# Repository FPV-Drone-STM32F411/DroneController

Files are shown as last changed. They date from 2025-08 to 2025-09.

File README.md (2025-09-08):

# FPV Drone PCB Full PCB + Code + Assembly

**A comprehensive, fully open-source FPV drone platform**: a two-board avionics stack (flight computer + power/ESC) complete with their codebase *and* a lightweight, robust airframe. All KiCad 9.0 design files, firmware, and CAD are included. Media of all PCBs, schematics and airframe are attached within this repository. 

## Overview

This project develops an FPV drone around two custom 5×5 PCBs: a **STM32F411 flight computer** and a **STM32F405 power distribution + ESC board**. esigned for compatibility with **Betaflight** (FC) and **AM32** (ESC). Both are built around the STM32 chipset and designed to be compatible with BetaFlight and AM32 requirements.

**Manufacturing Sponsor:** Huge thanks to **[PCBWay](https://www.pcbway.com/)** for sponsoring fabrication and assembly of the MKII flight computer. Their high-quality manufacturing, quick turnaround, significantly accelerated the build process. Moreover, their service was excellent and addressed questions promptly and clearly. As a bonus, PCBWay offers affordable, unique **silkscreen colours**. PCBWay is highly recommended and proved to be a great fit for the FPV-Drone-STM32F411 project.

**MKII Flight Computer 3D Model**



**What’s new (MKII & Airframe)**
- **MKII Flight Computer:** UART and SWD flash options, cost-efficient and compact IMU (ICM-42605), oscilloscope-friendly SPI test pads, expanded test points, JST connectors, improved routing for debugability.
- **Open-Source Airframe:** integrated landing legs, structural reinforcements, and geometry to accommodate **~935 KV BLDC motors**; CAD provided for easy printing/mods.

## Airframe

The airframe is designed to be **robust and lightweight** with:
- **Integrated landing legs** and **structural reinforcements** for durability  
- Geometry to suit **~935 KV** brushless motors (modeled in CAD)  
- CAD provided for printing and customization

**Printing tips (suggested):**
- Arms/plates: CF-reinforced nylon or strong PLA+/PETG  
- Landing legs: TPU for impact absorption
- Verify clearances for your chosen motor + prop combo (aimed at 5″ class)

## Hardware Details

 **Integrated PCB Design**
  - Flight Controller: STM32F411CEU6 (ARM Cortex M4)
  - Power/ESC Board: High-current paths, AM32 compatible design
    
 **Connectivity**
  - All peripherals utilize SPI for high-speed sensor communication
  - USB-C, JTAG, SWD
  - UART port for external peripheral
  - Backup Coin Cell Battery Port
  - FTDI programming interface

<ins>**Flight Controller Board**</ins>
- STM32F411CEU6 microcontroller
- 12MHz external crystal oscillator
- ICM-42605 gyroscope/accelerometer
- BMP280 barometer for altitude hold
- L86-M33 GPS for postional tracking
- SX 1276 LoRa 915MHz Transciever NiceRF Module
- Power options, USB-C, LDO and External 3.3V Connection

<ins>**Power and ESC Board**</ins>

**Power System**
- SWD Flash
- DC-DC buck converter for efficient power regulation
- Support for 3S-4S LiPo batteries (11.1V-16.8V)
- XT-60 connector for battery input
- Electric Speed Controller for a BLDC motor

**Electronic Speed Controller (ESC)**
- AM32 compatible
- 10A 935 KV motor capability
- Thermal management design

## Software Compatibility

This drone design is compatible with:
- BetaFlight (recommended for racing/freestyle)
- INAV (for GPS functions)
- Ardupilot (for autonomous capabilities)
- AM32 (for ESC functionality)
- STM32CUBEIDE (Coded in C for entire codebase)

### Bill of Materials

| Component | Description | Specification |
|---|---|---|
| Frame | Open-Source CAD | 5″ class geometry w/ landing legs |
| Motors | Brushless | 935 KV (example: 1800 KV 5″ also viable) |
| Battery | LiPo | 4S 1500mAh 100C (recommended) |
| Propellers | 5-inch | Matched to motor and frame |
| Camera | FPV | CCD or CMOS based on preference |
| Video Transmitter | 5.8GHz | Power output based on needs |
| Receiver | Radio control | Compatible with SX1276 LoRa Transciever |
| LoRa Antenna | 915MHz |SMA compatible quarter-wavelength antenna|

### Electronics Knowledge
- Basic soldering skills
- Understanding of power systems
- Familiarity with microcontrollers
- Ability to flash firmware through CUBEIDE

## Testing Procedures

1. Power system verification (voltage output, regulation)
2. Motor/ESC testing with oscillosocpe
3. SPI testing using oscciloscope test pads
4. Sensor calibration and verification
5. Radio range and failsafe testing
6. Controlled hover tests
7. Full flight testing

# Media
## Most Updated
### Airframe



### MKII of Flight Computer 

**MKII Flight Computer 3D Model**



**MKII Flight Computer PCB**

\

**MKI Flight Computer Schematic**


**MKII Flight Computer Firmware Data Acquistion**

***Disclaimer: GPS outputs are example outputs***

DATA

### MKI of Electric Speed Controller 

**MKI of ESC 3D Model**

ESCV1

**MKI of ESC PCB**



**MKI of ESC Schematic**



## Historical
### MKI of Flight Computer
**MKI Flight Computer 3D Model**



**MKI Flight Computer PCB**



**MKI Flight Computer Schematic**


## Collaboration

This project is in collaboration with Ammar Mahmood and esb8, all PCB designs, CAD modelling, firmware modifications, and build documentation are developed jointly to ensure the highest quality and performance.

## License

This project is released under the MIT License. All design files, including schematics, PCB layouts, and firmware modifications are open source and available for personal and commercial use with attribution.

## Resources

- [PCBWay](https://www.pcbway.com/)
- [BetaFlight Documentation](https://betaflight.com/docs/getting-started/installation)
- [STM32F4 Reference Manual](https://www.st.com/resource/en/reference_manual/rm0383-stm32f411xce-advanced-armbased-32bit-mcus-stmicroelectronics.pdf)
- [ESB8 GitHub Repository](https://github.com/esb8)
- [Ammar Github Repository](https://github.com/ammarjmahmood)
- [Project GitHub Repository](https://github.com/your-username/esb8-fpv-drone)

---
*This FPV drone project aims to combine and create a full documentation on the latest in drone technology with custom-designed electronics to create a high-performance, reliable platform for racing, freestyle, or aerial photography.*

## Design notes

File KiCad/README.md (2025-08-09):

# FPV Drone PCB Full PCB + Assembly

A comprehensive open-source avionics ecosystem for FPV drones featuring a completed flight computer PCB along with in-development power distribution and electronic speed controller PCB. This project delivers an avionics stack for a custom drone with full schematic and PCB files available on KiCad 9.0.

## Overview

This project aims to create a FPV drone with a custom all-in-one (AIO) PCB that combines the flight controller, power distribution, and ESC functionality. Built around the STM32F411CEU6 microcontroller, this drone follows BetaFlight and AM32 design requirements while providing a clean and efficient build.

## Hardware 

 **Integrated PCB Design**
  - Flight Controller: STM32F411CEU6 (ARM Cortex M4)
  - Power Distribution: High-current paths with filtering
  - ESC: AM32 compatible 4-in-1 design
    
 **Connectivity**
  - All peripherals utilize SPI for high-speed sensor communication
  - USB-C, JTAG, SWD
  - UART port for external peripheral
  - Backup Coin Cell Battery Port
  - FTDI programming interface

<ins>**Flight Controller Board**</ins>
- STM32F411CEU6 microcontroller
- 12MHz external crystal oscillator
- ICM-42605 gyroscope/accelerometer
- BMP280 barometer for altitude hold
- L86-M33 GPS for postional tracking
- SX 1276 LoRa 915MHz Transciever NiceRF Module
- Power options, USB-C, LDO and External 3.3V Connection

<ins>**Power and ESC Board**</ins>

**Power System**
- SWD Flash
- DC-DC buck converter for efficient power regulation
- Support for 3S-4S LiPo batteries (11.1V-16.8V)
- XT-60 connector for battery input
- Electric Speed Controller for four BLDC motors

**ESC (Electronic Speed Controller)**
- AM32 compatible
- 30A motor capability
- Thermal management design

## Software Compatibility

This drone design is compatible with:
- BetaFlight (recommended for racing/freestyle)
- INAV (for GPS functions)
- Ardupilot (for autonomous capabilities)
- AM32 (for ESC functionality)

### Bill of Materials

| Component | Description | Specification |
|---|---|---|
| Frame | 3D printed carbon fiber | 5" freestyle/racing frame |
| Motors | Brushless | SpeedyBee 1800KV (recommended) |
| Battery | LiPo | 4S 1500mAh 100C (recommended) |
| Propellers | 5-inch | Matched to motor and frame |
| Camera | FPV | CCD or CMOS based on preference |
| Video Transmitter | 5.8GHz | Power output based on needs |
| Receiver | Radio control | Compatible with SX1276 LoRa Transciever |
| LoRa Antenna | 915MHz |SMA compatible half-dipole antenna|

### Tools
- Soldering iron and solder
- Heat shrink tubing
- Hex drivers/screwdrivers
- LiPo battery charger
- Multimeter
- KiCAD for PCB design modifications
- Zip ties
- Double-sided foam tape

### Electronics Knowledge
- Basic soldering skills
- Understanding of power systems
- Familiarity with microcontrollers
- Ability to flash firmware

## Calculations

### Power System
- Max Current = 4 motors × 30A = 120A
- Required C Rating = 120A / 1.5Ah = 80C minimum
- Flight time estimate = (1500mAh) ÷ (Average current draw) × 60 × 0.8

### Weight Budget
- Target all-up-weight: ~500g (5" freestyle quad)
- Battery weight: ~120-150g (4S 1500mAh)
- Component weight distribution accordingly

## Testing Procedures

1. Power system verification (voltage output, regulation)
2. Motor/ESC testing with oscillosocpe
3. Sensor calibration and verification
4. Radio range and failsafe testing
5. Controlled hover tests
6. Full flight testing

# Media
### MKI of Electric Speed Controller (ESC)

**MKI of ESC 3D Model**



**MKI of ESC PCB**



**MKI of ESC Schematic**



### MKII of Flight Computer (Most Updated)

**MKII Flight Computer 3D Model**



**MKII Flight Computer PCB**



### MKII of Flight Computer
**MKI Flight Computer Schematic**


**MKI Flight Computer 3D Model**



**MKI Flight Computer PCB**



**MKI Flight Computer Schematic**


## Collaboration

This project is in collaboration with Ammar Mahmood and esb8, All PCB designs, firmware modifications, and build documentation are developed jointly to ensure the highest quality and performance.

## License

This project is released under the MIT License. All design files, including schematics, PCB layouts, and firmware modifications are open source and available for personal and commercial use with attribution.

## Resources

- [BetaFlight Documentation](https://betaflight.com/docs/getting-started/installation)
- [STM32F4 Reference Manual](https://www.st.com/resource/en/reference_manual/rm0383-stm32f411xce-advanced-armbased-32bit-mcus-stmicroelectronics.pdf)
- [ESB8 GitHub Repository](https://github.com/esb8)
- [Ammar Github Repository](https://github.com/ammarjmahmood)
- [Project GitHub Repository](https://github.com/your-username/esb8-fpv-drone)

## Contributing

We welcome contributions to this project! If you have suggestions, bug reports, or want to contribute code, please:
1. Fork the repository
2. Create a feature branch
3. Submit a pull request

---
*This FPV drone project aims to combine and create a full documentation on the latest in drone technology with custom-designed electronics to create a high-performance, reliable platform for racing, freestyle, or aerial photography.*

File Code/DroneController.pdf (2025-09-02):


29/08/2025

DroneController Project
Configuration Report

## 1. Description

### 1.1. Project

Project Name | DroneController
Board Name | custom
Generated with: | STM32CubeMX 6.15.0
Date | 08/29/2025

### 1.2. MCU

MCU Series | STM32F4
MCU Line | STM32F411
MCU name | STM32F411CEUx
MCU Package | UFQFPN48
MCU Pin number | 48

### 1.3. Core(s) information

Core(s) | Arm Cortex-M4

## 2. Pinout Configuration

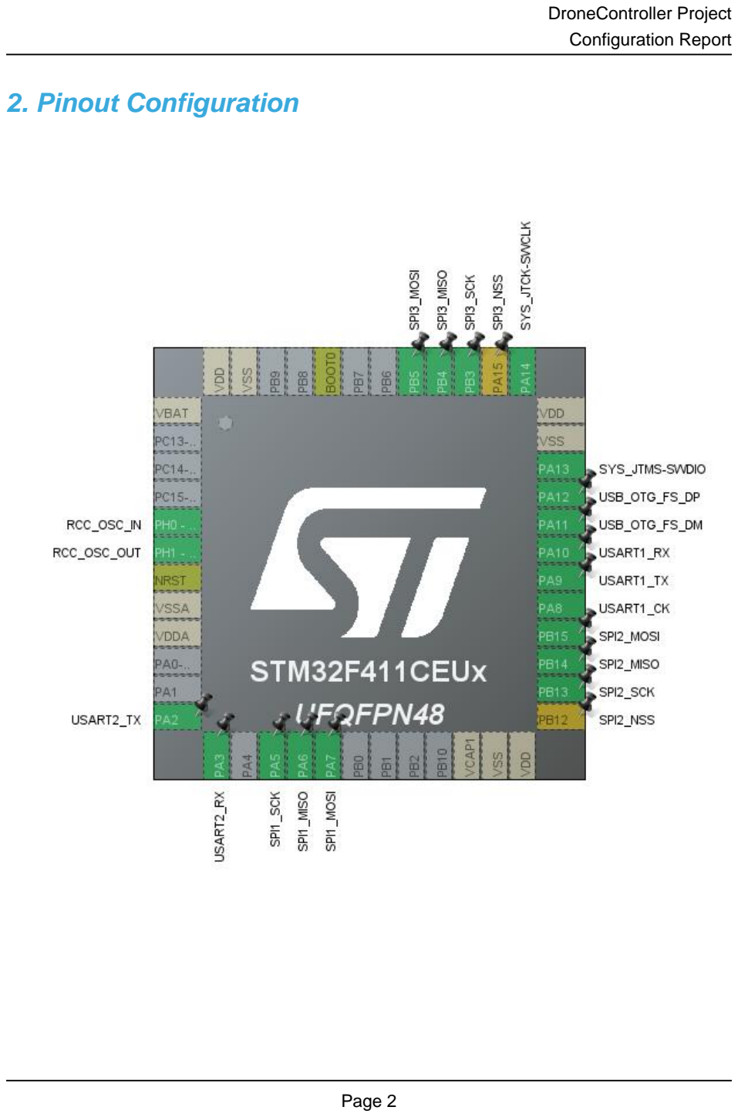
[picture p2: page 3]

## 3. Pins Configuration

Pin Number UFQFPN48 | Pin Name (function after reset) | Pin Type | Alternate Function(s) | Label
1 | VBAT | Power
5 | PH0 - OSC_IN | I/O | RCC_OSC_IN
6 | PH1 - OSC_OUT | I/O | RCC_OSC_OUT
7 | NRST | Reset
8 | VSSA | Power
9 | VDDA | Power
12 | PA2 | I/O | USART2_TX
13 | PA3 | I/O | USART2_RX
15 | PA5 | I/O | SPI1_SCK
16 | PA6 | I/O | SPI1_MISO
17 | PA7 | I/O | SPI1_MOSI
22 | VCAP1 | Power
23 | VSS | Power
24 | VDD | Power
25 | PB12 * | I/O | SPI2_NSS
26 | PB13 | I/O | SPI2_SCK
27 | PB14 | I/O | SPI2_MISO
28 | PB15 | I/O | SPI2_MOSI
29 | PA8 | I/O | USART1_CK
30 | PA9 | I/O | USART1_TX
31 | PA10 | I/O | USART1_RX
32 | PA11 | I/O | USB_OTG_FS_DM
33 | PA12 | I/O | USB_OTG_FS_DP
34 | PA13 | I/O | SYS_JTMS-SWDIO
35 | VSS | Power
36 | VDD | Power
37 | PA14 | I/O | SYS_JTCK-SWCLK
38 | PA15 * | I/O | SPI3_NSS
39 | PB3 | I/O | SPI3_SCK
40 | PB4 | I/O | SPI3_MISO
41 | PB5 | I/O | SPI3_MOSI
44 | BOOT0 | Boot
47 | VSS | Power
48 | VDD | Power

* The pin is affected with a peripheral function but no peripheral mode is activated

## 4. Clock Tree Configuration

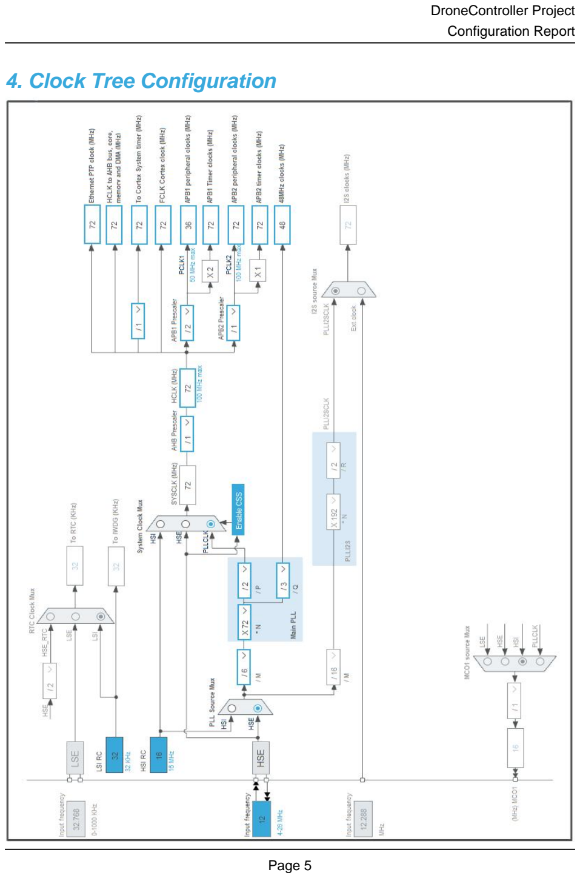
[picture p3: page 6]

## 1. Power Consumption Calculator report

### 1.1. Microcontroller Selection

Series | STM32F4
Line | STM32F411
MCU | STM32F411CEUx
Datasheet | DS10314_Rev6

### 1.2. Parameter Selection

Temperature | 25
Vdd | 1.7

### 1.3. Battery Selection

Battery | Li-SOCL2(A3400)
Capacity | 3400.0 mAh
Self Discharge | 0.08 %/month
Nominal Voltage | 3.6 V
Max Cont Current | 100.0 mA
Max Pulse Current | 200.0 mA
Cells in series | 1
Cells in parallel | 1

### 1.4. Sequence

Step | Step1 | Step2
Mode | RUN | STOP
Vdd | 1.7 | 1.7
Voltage Source | Battery | Battery
Range | Scale1-High | No Scale
Fetch Type | SRAM | n/a
CPU Frequency | 100 MHz | 0 Hz
Clock Configuration | HSE PLL | Regulator_LPLV Flash-PwrDwn
Clock Source Frequency | 4 MHz | 0 Hz
Peripherals
Additional Cons. | 0 mA | 0 mA
Average Current | 12.7 mA | 9 µA
Duration | 0.1 ms | 0.9 ms
DMIPS | 125.0 | 0.0
Ta Max | 104.31 | 105
Category | In DS Table | In DS Table

### 1.5. Results

Sequence Time | 1 ms | Average Current | 1.28 mA
Battery Life | 3 months, 19 days, 6 hours | Average DMIPS | 125.0 DMIPS

### 1.6. Chart

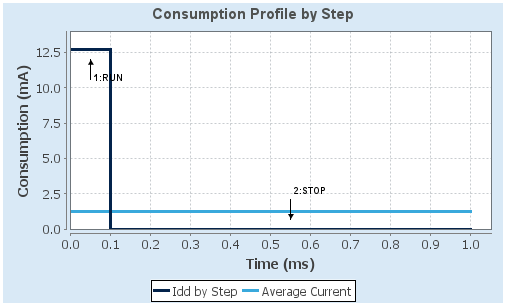
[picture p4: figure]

## 2. Software Project

### 2.1. Project Settings

Name | Value
Project Name | DroneController
Project Folder | C:\Users\evanb\STM32CubeIDE\workspace_1.19.0\DroneController
Toolchain / IDE | STM32CubeIDE
Firmware Package Name and Version | STM32Cube FW_F4 V1.28.3
Application Structure | Advanced
Generate Under Root | Yes
Do not generate the main() | No
Minimum Heap Size | 0x200
Minimum Stack Size | 0x400

### 2.2. Code Generation Settings

Name | Value
STM32Cube MCU packages and embedded software | Copy only the necessary library files
Generate peripheral initialization as a pair of '.c/.h' files | No
Backup previously generated files when re-generating | No
Keep User Code when re-generating | Yes
Delete previously generated files when not re-generated | Yes
Set all free pins as analog (to optimize the power consumption) | No
Enable Full Assert | No

### 2.3. Advanced Settings - Generated Function Calls

Rank | Function Name | Peripheral Instance Name
1 | SystemClock_Config | RCC
2 | MX_GPIO_Init | GPIO
3 | MX_SPI1_Init | SPI1
4 | MX_SPI2_Init | SPI2
5 | MX_SPI3_Init | SPI3
6 | MX_USART1_Init | USART1
7 | MX_USART2_UART_Init | USART2
8 | MX_USB_DEVICE_Init | USB_DEVICE

## 3. Peripherals and Middlewares Configuration

### 3.1. RCC

High Speed Clock (HSE): Crystal/Ceramic Resonator
3.1.1. Parameter Settings:

System Parameters:

VDD voltage (V) | 3.3
Instruction Cache | Enabled
Prefetch Buffer | Enabled
Data Cache | Enabled
Flash Latency(WS) | 2 WS (3 CPU cycle)
RCC Parameters:
HSI Calibration Value | 16
TIM Prescaler Selection | Disabled
HSE Startup Timout Value (ms) | 100
LSE Startup Timout Value (ms) | 5000
Power Parameters:
Power Regulator Voltage Scale | Power Regulator Voltage Scale 1

### 3.2. SPI1

Mode: Full-Duplex Master
3.2.1. Parameter Settings:

Basic Parameters:

Frame Format | Motorola
Data Size | 8 Bits
First Bit | MSB First
Clock Parameters:
Prescaler (for Baud Rate) | 4 *
Baud Rate | 18.0 MBits/s *
Clock Polarity (CPOL) | Low
Clock Phase (CPHA) | 1 Edge
Advanced Parameters:
CRC Calculation | Disabled
NSS Signal Type | Software

### 3.3. SPI2

Mode: Full-Duplex Master
3.3.1. Parameter Settings:

Basic Parameters:

Frame Format | Motorola
Data Size | 8 Bits
First Bit | MSB First
Clock Parameters:
Prescaler (for Baud Rate) | 2
Baud Rate | 18.0 MBits/s *
Clock Polarity (CPOL) | Low
Clock Phase (CPHA) | 1 Edge
Advanced Parameters:
CRC Calculation | Disabled
NSS Signal Type | Software

### 3.4. SPI3

Mode: Full-Duplex Master
3.4.1. Parameter Settings:

Basic Parameters:

Frame Format | Motorola
Data Size | 8 Bits
First Bit | MSB First
Clock Parameters:
Prescaler (for Baud Rate) | 2
Baud Rate | 18.0 MBits/s *
Clock Polarity (CPOL) | Low
Clock Phase (CPHA) | 1 Edge
Advanced Parameters:
CRC Calculation | Disabled
NSS Signal Type | Software

### 3.5. SYS

Debug: Serial Wire
Timebase Source: SysTick

### 3.6. USART1

Mode: Synchronous
3.6.1. Parameter Settings:

Basic Parameters:

Baud Rate | 115200
Word Length | 8 Bits (including Parity)
Parity | None
Stop Bits | 1
Advanced Parameters:
Data Direction | Receive and Transmit
Clock Parameters:
Clock Polarity | Low
Clock Phase | One Edge
Clock Last Bit | Disable

### 3.7. USART2

Mode: Asynchronous
3.7.1. Parameter Settings:

Basic Parameters:

Baud Rate | 115200
Word Length | 8 Bits (including Parity)
Parity | None
Stop Bits | 1
Advanced Parameters:
Data Direction | Receive and Transmit
Over Sampling | 16 Samples

### 3.8. USB_OTG_FS

Mode: Device_Only

3.8.1. Parameter Settings:
Speed | Device Full Speed 12MBit/s
Low power | Disabled
Link Power Management | Disabled
VBUS sensing | Disabled
Signal start of frame | Disabled

### 3.9. USB_DEVICE

Class For FS IP: Communication Device Class (Virtual Port Com)
3.9.1. Parameter Settings:

Basic Parameters:

USBD_MAX_NUM_INTERFACES (Maximum number of supported interfaces) | 1
USBD_MAX_NUM_CONFIGURATION (Maximum number of supported configuration) | 1
USBD_MAX_STR_DESC_SIZ (Maximum size for the string descriptors) | 512
USBD_SELF_POWERED (Enabled self power) | Enabled
USBD_DEBUG_LEVEL (USBD Debug Level) | 0: No debug message
Class Parameters:
USB CDC Rx Buffer Size | 2048
USB CDC Tx Buffer Size | 2048
3.9.2. Device Descriptor:

Device Descriptor:

VID (Vendor IDentifier) | 1155
LANGID_STRING (Language Identifier) | English(United States)
MANUFACTURER_STRING (Manufacturer Identifier) | STMicroelectronics
Device Descriptor FS:
PID (Product IDentifier) | 22336
PRODUCT_STRING (Product Identifier) | STM32 Virtual ComPort
CONFIGURATION_STRING (Configuration Identifier) | CDC Config
INTERFACE_STRING (Interface Identifier) | CDC Interface

* User modified value

## 4. System Configuration

### 4.1. GPIO configuration

IP | Pin | Signal | GPIO mode | GPIO pull/up pull down

Max
Speed

User Label

RCC | PH0 - OSC_IN | RCC_OSC_IN | n/a | n/a | n/a
| PH1 - OSC_OUT | RCC_OSC_OUT | n/a | n/a | n/a
SPI1 | PA5 | SPI1_SCK | Alternate Function Push Pull | No pull-up and no pull-down | Very High
*
| PA6 | SPI1_MISO | Alternate Function Push Pull | No pull-up and no pull-down | Very High
*
| PA7 | SPI1_MOSI | Alternate Function Push Pull | No pull-up and no pull-down | Very High
*
SPI2 | PB13 | SPI2_SCK | Alternate Function Push Pull | No pull-up and no pull-down | Very High
*
| PB14 | SPI2_MISO | Alternate Function Push Pull | No pull-up and no pull-down | Very High
*
| PB15 | SPI2_MOSI | Alternate Function Push Pull | No pull-up and no pull-down | Very High
*
SPI3 | PB3 | SPI3_SCK | Alternate Function Push Pull | No pull-up and no pull-down | Very High
*
| PB4 | SPI3_MISO | Alternate Function Push Pull | No pull-up and no pull-down | Very High
*
| PB5 | SPI3_MOSI | Alternate Function Push Pull | No pull-up and no pull-down | Very High
*
SYS | PA13 | SYS_JTMS- SWDIO | n/a | n/a | n/a
| PA14 | SYS_JTCK- SWCLK | n/a | n/a | n/a
USART1 | PA8 | USART1_CK | Alternate Function Push Pull | No pull-up and no pull-down | Very High
*
| PA9 | USART1_TX | Alternate Function Push Pull | No pull-up and no pull-down | Very High
*
| PA10 | USART1_RX | Alternate Function Push Pull | No pull-up and no pull-down | Very High
*
USART2 | PA2 | USART2_TX | Alternate Function Push Pull | No pull-up and no pull-down | Very High
*

IP | Pin | Signal | GPIO mode | GPIO pull/up pull down | Max Speed | User Label
| PA3 | USART2_RX | Alternate Function Push Pull | No pull-up and no pull-down | Very High *
USB_OTG_ FS | PA11 | USB_OTG_FS_ DM | Alternate Function Push Pull | No pull-up and no pull-down | Very High *
| PA12 | USB_OTG_FS_ DP | Alternate Function Push Pull | No pull-up and no pull-down | Very High *
Single Mapped Signals | PB12 | SPI2_NSS | Alternate Function Push Pull | No pull-up and no pull-down | Very High *
| PA15 | SPI3_NSS | Alternate Function Push Pull | No pull-up and no pull-down | Very High *

### 4.2. DMA configuration

nothing configured in DMA service

### 4.3. NVIC configuration

4.3.1. NVIC
Interrupt Table | Enable | Preenmption Priority | SubPriority
Non maskable interrupt | true | 0 | 0
Hard fault interrupt | true | 0 | 0
Memory management fault | true | 0 | 0
Pre-fetch fault, memory access fault | true | 0 | 0
Undefined instruction or illegal state | true | 0 | 0
System service call via SWI instruction | true | 0 | 0
Debug monitor | true | 0 | 0
Pendable request for system service | true | 0 | 0
System tick timer | true | 15 | 0
USB On The Go FS global interrupt | true | 0 | 0
PVD interrupt through EXTI line 16 | unused
Flash global interrupt | unused
RCC global interrupt | unused
SPI1 global interrupt | unused
SPI2 global interrupt | unused
USART1 global interrupt | unused
USART2 global interrupt | unused
SPI3 global interrupt | unused
FPU global interrupt | unused
4.3.2. NVIC Code generation
Enabled interrupt Table | Select for init sequence ordering | Generate IRQ handler | Call HAL handler
Non maskable interrupt | false | true | false
Hard fault interrupt | false | true | false
Memory management fault | false | true | false
Pre-fetch fault, memory access fault | false | true | false
Undefined instruction or illegal state | false | true | false
System service call via SWI instruction | false | true | false
Debug monitor | false | true | false
Pendable request for system service | false | true | false
System tick timer | false | true | true
USB On The Go FS global interrupt | false | true | true

* User modified value

## 5. System Views

5.1. Category view
5.1.1. Current

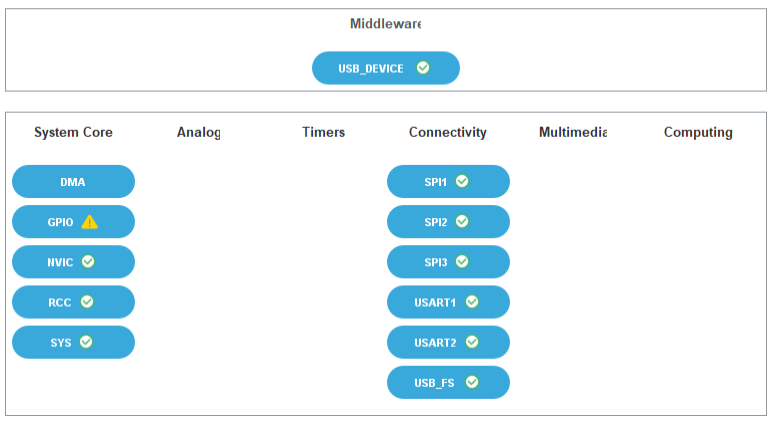
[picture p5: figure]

## 6. Docs & Resources

Type | Link
BSDL files | https://www.st.com/resource/en/bsdl_model/stm32f411_bsdl.zip
IBIS models | https://www.st.com/resource/en/ibis_model/stm32f411_ibis.zip
System View Description | https://www.st.com/resource/en/svd/stm32f4-svd.zip
Presentations | https://www.st.com/resource/en/product_presentation/stm32-stm8_embedded_software_solutions.pdf
Presentations | https://www.st.com/resource/en/product_presentation/stm32_eval-tools_portfolio.pdf
Presentations | https://www.st.com/resource/en/product_presentation/stm32_stm8_functi onal-safety-packages.pdf
Presentations | https://www.st.com/resource/en/product_presentation/stm32-stm8_software_development_tools.pdf
Presentations | https://www.st.com/resource/en/product_presentation/microcontrollers-stm32-family-overview.pdf
Brochures | https://www.st.com/resource/en/brochure/products-and-solutions-for-plcs-and-smart-i-os.pdf
Flyers | https://www.st.com/resource/en/flyer/flstm32f4x1.pdf
Flyers | https://www.st.com/resource/en/flyer/flstm32nucleo.pdf
Flyers | https://www.st.com/resource/en/flyer/flstm32trust.pdf
Product Certifications | https://www.st.com/resource/en/certification_document/stm32_authentication_can.pdf
Security Bulletin | https://www.st.com/resource/en/technical_note/tn1489-security-bulletin-tn1489stpsirt-physical-attacks-on-stm32-and-stm32cube-firmware-stmicroelectronics.pdf
Application Notes | https://www.st.com/resource/en/application_note/an1709-emc-design-guide-for-stm8-stm32-and-legacy-mcus-stmicroelectronics.pdf
Application Notes | https://www.st.com/resource/en/application_note/an2606-stm32-microcontroller-system-memory-boot-mode-stmicroelectronics.pdf
Application Notes | https://www.st.com/resource/en/application_note/an2945-stm8s-and-

| stm32-mcus-a-consistent-832bit-product-line-for-painless-migration-stmicroelectronics.pdf
Application Notes | https://www.st.com/resource/en/application_note/an3070-managing-the-driver-enable-signal-for-rs485-and-iolink-communications-with-the-stm32s-usart-stmicroelectronics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
Application Notes | https://www.st.com/resource/en/application_note/an3126-audio-and-waveform-generation-using-the-dac-in-stm32-products-stmicroelectronics.pdf
Application Notes | https://www.st.com/resource/en/application_note/an3155-usart-protocol-used-in-the-stm32-bootloader-stmicroelectronics.pdf
Application Notes | https://www.st.com/resource/en/application_note/an3156-usb-dfu-protocol-used-in-the-stm32-bootloader-stmicroelectronics.pdf
Application Notes | https://www.st.com/resource/en/application_note/an3364-migration-and-compatibility-guidelines-for-stm32-microcontroller-applications-stmicroelectronics.pdf
Application Notes | https://www.st.com/resource/en/application_note/an3997-audio-playback-and-recording-using-the-stm32f4discovery-stmicroelectronics.pdf
Application Notes | https://www.st.com/resource/en/application_note/an3998-pdm-audio-software-decoding-on-stm32-microcontrollers-stmicroelectronics.pdf
Application Notes | https://www.st.com/resource/en/application_note/an4031-using-the-stm32f2-stm32f4-and-stm32f7-series-dma-controller-stmicroelectronics.pdf
Application Notes | https://www.st.com/resource/en/application_note/an4221-i2c-protocol-used-in-the-stm32-bootloader-stmicroelectronics.pdf
Application Notes | https://www.st.com/resource/en/application_note/an4286-spi-protocol-used-in-the-stm32-bootloader-stmicroelectronics.pdf
Application Notes | https://www.st.com/resource/en/application_note/an4488-getting-started-with-stm32f4xxxx-mcu-hardware-development-stmicroelectronics.pdf
Application Notes | https://www.st.com/resource/en/application_note/an4616-migrating-from-stm32f401-and-stm32f411-lines-to-stm32l4-series-and-stm32l4-series-microcontrollers-stmicroelec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
Application Notes | https://www.st.com/resource/en/application_note/an4646-peripheral- interconnections-on-stm32f401-and-stm32f411-lines-

| stmicroelectronics.pdf
Application Notes | https://www.st.com/resource/en/application_note/an4655-virtually-increasing-the-number-of-serial-communication-peripherals-in-stm32-applications-stmicroelectronics.p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
Application Notes | https://www.st.com/resource/en/application_note/an4739-stm32cube-firmware-examples-for-stm32f4-series-stmicroelectronics.pdf
Application Notes | https://www.st.com/resource/en/application_note/an4750-handling-of-soft-errors-in-stm32-applications-stmicroelectronics.pdf
Application Notes | https://www.st.com/resource/en/application_note/an4776-generalpurpose-timer-cookbook-for-stm32-microcontrollers-stmicroelectronics.pdf
Application Notes | https://www.st.com/resource/en/application_note/an4803-highspeed-si-simulations-using-ibis-and-boardlevel-simulations-using-hyperlynx-si-on-stm32-mcus-and-mpus-stmic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
Application Notes | https://www.st.com/resource/en/application_note/an4850-stm32-mcus-spreadspectrum-clock-generation-principles-properties-and-implementation-stmicroelectronics.pdf
Application Notes | https://www.st.com/resource/en/application_note/an4904-migration-of-microcontroller-applications-from-stm32f1-series-to-stm32f4-access-lines-stmicroelectronics.pdf
Application Notes | https://www.st.com/resource/en/application_note/an4989-stm32-microcontroller-debug-toolbox-stmicroelectronics.pdf
Application Notes | https://www.st.com/resource/en/application_note/an4995-using-an-electromyogram-technique-to-detect-muscle-activity-stmicroelectronics.pdf
Application Notes | https://www.st.com/resource/en/application_note/an5027-interfacing-pdm-digital-microphones-using-stm32-mcus-and-mpus-stmicroelectronics.pdf
Application Notes | https://www.st.com/resource/en/application_note/an5073-receiving-spdif-audio-stream-with-the-stm32f4f7h7-series-stmicroelectronics.pdf
Application Notes | https://www.st.com/resource/en/application_note/an4899-stm32-microcontroller-gpio-hardware-settings-and-lowpower-consumption-stmicroelectronics.pdf
Application Notes | https://www.st.com/resource/en/application_note/an5612-esd-protection-of-stm32-mcus-and-mpus-stmicroelectronics.pdf

Application Notes | https://www.st.com/resource/en/application_note/an4838-introduction-to-memory-protection-unit-management-on-stm32-mcus-stmicroelectronics.pdf
Application Notes | https://www.st.com/resource/en/application_note/an5852-migrating-from-stm32f401-stm32f410-and-stm32f411-to-stm32h503-mcus-stmicroelectronics.pdf
Application Notes | https://www.st.com/resource/en/application_note/an4879-introduction-to-usb-hardware-and-pcb-guidelines-using-stm32-mcus-stmicroelectronics.pdf
Application Notes | https://www.st.com/resource/en/application_note/an5225-introduction-to-usb-typec-power-delivery-for-stm32-mcus-and-mpus-stmicroelectronics.pdf
Application Notes | https://www.st.com/resource/en/application_note/an5537-how-to-use-adc-oversampling-techniques-to-improve-signaltonoise-ratio-on-stm32-mcus-stmicroelectronics.pdf
Application Notes | https://www.st.com/resource/en/application_note/an5036-guidelines-for-thermal-management-on-stm32-applications-stmicroelectronics.pdf
Application Notes | https://www.st.com/resource/en/application_note/an4230-introduction-to-random-number-generation-validation-using-the-nist-statistical-test-suite-for-stm32-mcus-and-m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
Application Notes | https://www.st.com/resource/en/application_note/an2867-guidelines-for-oscillator-design-on-stm8afals-and-stm32-mcusmpus-stmicroelectronics.pdf
Application Notes | https://www.st.com/resource/en/application_note/an4013-introduction-to-timers-for-stm32-mcus-stmicroelectronics.pdf
Application Notes | https://www.st.com/resource/en/application_note/an4277-how-to-use-pwm-shutdown-for-motor-control-and-digital-power-conversion-on-stm32-mcus-stmicroelectronics.pdf
Application Notes | https://www.st.com/resource/en/application_note/an4759-introduction-to-using-the-hardware-realtime-clock-rtc-and-the-tamper-management-unit-tamp-with-stm32-mcus-stmi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
Application Notes | https://www.st.com/resource/en/application_note/an4908-getting-started-with-usart-automatic-baud-rater-detection-for-stm32-mcus-stmicroelectronics.pdf

Application Notes | https://www.st.com/resource/en/application_note/an5156-introduction-to-security-for-stm32-mcus-stmicroelectronics.pdf
Application Notes | https://www.st.com/resource/en/application_note/an5543-guidelines-for-enhanced-spi-communication-on-stm32-mcus-and-mpus-stmicroelectronics.pdf
Application Notes | https://www.st.com/resource/en/application_note/cd00211314-how-to-optimize-the-adc-accuracy-in-the-stm32-mcus-stmicroelectronics.pdf
Application Notes | https://www.st.com/resource/en/application_note/an2639-soldering-recommendations-and-package-information-for-leadfree-ecopack2-mcus-and-mpus-stmicroelectronics.pdf
Application Notes | https://www.st.com/resource/en/application_note/an3154-how-to-use-can-protocol-in-bootloader-on-stm32-mcus-stmicroelectronics.pdf
Application Notes | https://www.st.com/resource/en/application_note/an4566-how-to-extend-the-dac-performance-on-stm32-mcus-stmicroelectronics.pdf
Application Notes for related Tools & Software | https://www.st.com/resource/en/application_note/an2656-stm32f10xxx-lcd-glass-driver-firmware-stmicroelectronics.pdf
Application Notes for related Tools & Software | https://www.st.com/resource/en/application_note/an2790-tft-lcd-interfacing-with-the-highdensity-stm32f10xxx-fsmc-stmicroelectronics.pdf
Application Notes for related Tools & Software | https://www.st.com/resource/en/application_note/an3078-stm32-inapplication-programming-over-the-ic-bus-stmicroelectronics.pdf
Application Notes for related Tools & Software | https://www.st.com/resource/en/application_note/an3116-stm32s-adc-modes-and-their-applications-stmicroelectronics.pdf
Application Notes for related Tools & Software | https://www.st.com/resource/en/application_note/an3174-implementing-receivers-for-infrared-remote-control-protocols-using-stm32f10xxx-microcontrollers-stmicroelectro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
Application Notes for related Tools & Software | https://www.st.com/resource/en/application_note/an3241-qvga-tftlcd-direct-drive-using-the-stm32f10xx-fsmc-peripheral-stmicroelectronics.pdf

Application Notes
for related Tools

https://www.st.com/resource/en/application_note/an3307-guidelines-forobtaining-iec-60335-class-b-certification-for-any-stm32-application-

& Software | stmicroelectronics.pdf
Application Notes for related Tools & Software | https://www.st.com/resource/en/application_note/an3965-stm32f40xstm32f41x-inapplication-programming-using-the-usart-stmicroelectronics.pdf
Application Notes for related Tools & Software | https://www.st.com/resource/en/application_note/an3969-eeprom-emulation-in-stm32f40xstm32f41x-microcontrollers-stmicroelectronics.pdf
Application Notes for related Tools & Software | https://www.st.com/resource/en/application_note/an4044-floating-point-unit-demonstration-on-stm32-microcontrollers-stmicroelectronics.pdf
Application Notes for related Tools & Software | https://www.st.com/resource/en/application_note/an4323-getting-started-with-stemwin-library-stmicroelectronics.pdf
Application Notes for related Tools & Software | https://www.st.com/resource/en/application_note/an4365-using-stm32f4-mcu-power-modes-with-best-dynamic-efficiency-stmicroelectronics.pdf
Application Notes for related Tools & Software | https://www.st.com/resource/en/application_note/an4435-guidelines-for-obtaining-ulcsaiec-607301603351-class-b-certification-in-any-stm32-application-stmicroelectroni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
Application Notes for related Tools & Software | https://www.st.com/resource/en/application_note/an4457-implementing-an-emulated-uart-on-stm32f4-microcontrollers-stmicroelectronics.pdf
Application Notes for related Tools & Software | https://www.st.com/resource/en/application_note/an4499-stm32--nrf51822-bluetooth-low-energy-system-solution-stmicroelectronics.pdf
Application Notes for related Tools & Software | https://www.st.com/resource/en/application_note/an4515-using-batch-acquisition-mode-bam-to-maximize-power-efficiency-on-stm32f410-stm32f411-stm32f412-stm32f413-micro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
Application Notes for related Tools & Software | https://www.st.com/resource/en/application_note/an4657-stm32-inapplication-programming-iap-using-the-usart-stmicroelectronics.pdf

Application Notes
for related Tools

https://www.st.com/resource/en/application_note/an4666-parallelsynchronous-transmission-using-gpio-and-dma-stmicroelectronics.pdf

& Software
Application Notes for related Tools & Software | https://www.st.com/resource/en/application_note/an4678-full-duplex-spi-emulation-for-stm32f4-microcontrollers-stmicroelectronics.pdf
Application Notes for related Tools & Software | https://www.st.com/resource/en/application_note/an4701-proprietary-code-readout-protection-on-microcontrollers-of-the-stm32f4-series-stmicroelectronics.pdf
Application Notes for related Tools & Software | https://www.st.com/resource/en/application_note/an4739-stm32cube-firmware-examples-for-stm32f4-series-stmicroelectronics.pdf
Application Notes for related Tools & Software | https://www.st.com/resource/en/application_note/an4758-proprietary-code-readout-protection-on-stm32l4-stm32l4-stm32g4-and-stm32wb-series-mcus-stmicroelectronics.pdf
Application Notes for related Tools & Software | https://www.st.com/resource/en/application_note/an4841-digital-signal-processing-for-stm32-microcontrollers-using-cmsis-stmicroelectronics.pdf
Application Notes for related Tools & Software | https://www.st.com/resource/en/application_note/an4968-proprietary-code-read-out-protection-pcrop-on-stm32f72xxx-and-stm32f73xxx-microcontrollers-stmicroelectronics.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
Application Notes for related Tools & Software | https://www.st.com/resource/en/application_note/an5056-integration-guide-for-the-xcubesbsfu-stm32cube-expansion-package-stmicroelectronics.pdf
Application Notes for related Tools & Software | https://www.st.com/resource/en/application_note/an5360-getting-started-with-projects-based-on-the-stm32mp1-series-in-stm32cubeide-stmicroelectronics.pdf
Application Notes for related Tools & Software | https://www.st.com/resource/en/application_note/an5361-getting-started-with-projects-based-on-dualcore-stm32h7-microcontrollers-in-stm32cubeide-stmicroelectronics.pd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
Application Notes for related Tools & Software | https://www.st.com/resource/en/application_note/an5394-getting-started-with-projects-based-on-the-stm32l5-series-in-stm32cubeide-stmicroelectronics.pdf
Application Notes for related Tools & Software | https://www.st.com/resource/en/application_note/an5418-how-to-build-a-simple-usbpd-sink-application-with-stm32cubemx-stmicroelectronics.pdf

Application Notes for related Tools & Software | https://www.st.com/resource/en/application_note/an5426-migrating-graphics-middleware-projects-from-stm32cubemx-540-to-stm32cubemx-550-stmicroelectronics.pdf
Application Notes for related Tools & Software | https://www.st.com/resource/en/application_note/an5464-position-control-of-a-threephase-permanent-magnet-motor-using-xcubemcsdk-or-xcubemcsdkful-stmicroelectronics.p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
Application Notes for related Tools & Software | https://www.st.com/resource/en/application_note/an5564-getting-started-with-projects-based-on-dualcore-stm32wl-microcontrollers-in-stm32cubeide-stmicroelectronics.pd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
Application Notes for related Tools & Software | https://www.st.com/resource/en/application_note/an5698-adapting-the-xcubestl-functional-safety-package-for-stm32-iec-61508-compliant-to-other-safety-standards-stmicr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
Application Notes for related Tools & Software | https://www.st.com/resource/en/application_note/an5731-stm32cubemx-and-stm32cubeide-threadsafe-solution-stmicroelectronics.pdf
Application Notes for related Tools & Software | https://www.st.com/resource/en/application_note/an4502-stm32-smbuspmbus-expansion-package-for-stm32cube-stmicroelectronics.pdf
Application Notes for related Tools & Software | https://www.st.com/resource/en/application_note/an5952-how-to-use-cmake-in-stm32cubeide-stmicroelectronics.pdf
Application Notes for related Tools & Software | https://www.st.com/resource/en/application_note/an5054-how-to-perform-secure-programming-using-stm32cubeprogrammer-stmicroelectronics.pdf
Application Notes for related Tools & Software | https://www.st.com/resource/en/application_note/an6179-how-to-integrate-the-stl-firmware-into-a-time-critical-user-application-stmicroelectronics.pdf
Application Notes for related Tools & Software | https://www.st.com/resource/en/application_note/an6127-getting-started-with-stm32h7rx7sx-mcus-in-stm32cubeide-stmicroelectronics.pdf
Design Notes & Tips | https://www.st.com/resource/en/design_tip/dt0088-fir-filter-design-by-sampling-windowing-and-modulating-the-sinc-function-stmicroelectronics.pdf
Design Notes & | https://www.st.com/resource/en/design_tip/dt0089-the-goertzel-algorithm-

Tips | to-compute-individual-terms-of-the-discrete-fourier-transform-dft-stmicroelectronics.pdf
Design Notes & Tips | https://www.st.com/resource/en/design_tip/dt0091-lattice-wave-digital-filter-design-and-automatic-c-code-generation-stmicroelectronics.pdf
Design Notes & Tips | https://www.st.com/resource/en/design_tip/dt0092-lattice-wave-digital-filter-test-and-performance-verification-stmicroelectronics.pdf
Device Option Lists | https://www.st.com/resource/en/device_option_list/opl_stm32f411_512k.zi p
Errata Sheets | https://www.st.com/resource/en/errata_sheet/es0287-stm32f411xcxe-device-errata-stmicroelectronics.pdf
Datasheet | https://www.st.com/resource/en/datasheet/dm00115249.pdf
Programming Manuals | https://www.st.com/resource/en/programming_manual/pm0214-stm32-cortexm4-mcus-and-mpus-programming-manual-stmicroelectronics.pdf
Reference Manuals | https://www.st.com/resource/en/reference_manual/rm0383-stm32f411xce-advanced-armbased-32bit-mcus-stmicroelectronics.pdf
Technical Notes & Articles | https://www.st.com/resource/en/technical_note/tn0516-overview-of-the-stm32f0xf100xxf103xx-and-stm32f2xxf30xf4xx-mcus-pmsm-singledual-foc-sdk-v40-stmicroelectronics.p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
Technical Notes & Articles | https://www.st.com/resource/en/technical_note/tn1163-description-of-wlcsp-for-microcontrollers-and-recommendations-for-its-use-stmicroelectronics.pdf
Technical Notes & Articles | https://www.st.com/resource/en/technical_note/tn1204-tape-and-reel-shipping-media-for-stm32-microcontrollers-in-bga-packages-stmicroelectronics.pdf
Technical Notes & Articles | https://www.st.com/resource/en/technical_note/tn1205-tape-and-reel-shipping-media-for-stm8-and-stm32-microcontrollers-in-fpn-packages-stmicroelectronics.pdf
Technical Notes & Articles | https://www.st.com/resource/en/technical_note/tn1206-tape-and-reel-shipping-media-for-stm8-and-stm32-microcontrollers-in-qfp-packages-stmicroelectronics.pdf
Technical Notes & Articles | https://www.st.com/resource/en/technical_note/tn1207-tape-and-reel-shipping-media-for-stm8-and-stm32-microcontrollers-in-so-packages-stmicroelectronics.pdf

Technical Notes & Articles | https://www.st.com/resource/en/technical_note/tn1208-tape-and-reel-shipping-media-for-stm8-and-stm32-microcontrollers-in-tssop-and-ssop-packages-stmicroelectronics.p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
Technical Notes & Articles | https://www.st.com/resource/en/technical_note/tn1433-reference-device-marking-schematics-for-stm32-microcontrollers-and-microprocessors-stmicroelectronics.pdf
User Manuals | https://www.st.com/resource/en/user_manual/um3461-stm32f4-series-ulcsaiec-607301603351-selftest-library-user-guide-stmicroelectronics.pdf

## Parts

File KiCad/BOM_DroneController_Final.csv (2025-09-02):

Item # | *Designator | *Qty | Manufacturer | *Mfg Part # | Description / Value | Vendor Part # | *Package/Footprint | Mounting Type | Category | *Unit Price(2 sets) | *Total | *Delivery Time | *Actual Purchase Mfg Part # | *PCBWay Note | Customer Reply
1 | +3.3V, BATT, UART2 | 3 |  | B2B-XH-A(LF)(SN) | Generic connectable mounting pin connector, single row, 01x02, script generated (kicad-library-utils/schlib/autogen/connector/) | C158012 | CONN-TH_B2B-XH-A-LF-SN | tht |  | $0.158 | $0.948 |  | B2B-XH-A(LF)(SN) | The quoted part number is [Connector], not [B2B-XH-A] as specified in description It's quoted based on the LCSC part you listed in this BOM.Please confirm if the part listed in the column of *Actual Purchase Mfg Part # is the correct one you need. | B2B-XH-A(LF)(SN) is correct.
2 | AE1 | 1 |  | BWSMA-KWE-Z001 | Antenna | C496551 | SMA_BAT_Wireless_BWSMA-KWE-Z001 | tht |  | $0.310 | $0.620 |  | BWSMA-KWE-Z001 | The quoted part number is [915MHZ Antenna], not [BWSMA-KWE-Z001] as specified in description It's quoted based on the LCSC part you listed in this BOM.Please confirm if the part listed in the column of *Actual Purchase Mfg Part # is the correct one you need. | BWSMA-KWE-Z001 is correct
3 | BOOT | 1 |  | MST-22D18G2 3J |  | C2875122 | SPDT | smt |  |  |  |  | MST-22D18G2 3J | Please provide exact part number or component URL. | C2875122, MFG part is MST-22D18G2 3J
4 | C10, C11 | 2 | FH(Guangdong Fenghua Advanced Tech) | 0402CG200J500NT | 50V 20pF C0G ±5% 0402 Multilayer Ceramic Capacitors MLCC - SMD/SMT ROHS『 』50V『 』±5%『 』20pF『 』C0G | C1554 | C_0402 | smt『 』SMT | Capacitors,Multilayer Ceramic Capacitors MLCC - SMD/SMT | $0.009 | $0.036 |  | 0402CG200J500NT
5 | C12, C17, C20, C25, C27, C28, C29, C31, C6, C9 | 10 | Samsung Electro-Mechanics | CL05B104KO5NNNC | 16V 100nF X7R ±10% 0402 Multilayer Ceramic Capacitors MLCC - SMD/SMT ROHS『 』16V『 』±10%『 』100nF『 』X7R | C1525 | C_0402 | smt『 』SMT | Capacitors,Multilayer Ceramic Capacitors MLCC - SMD/SMT | $0.008 | $0.160 |  | CL05B104KO5NNNC
6 | C14 | 1 | Samsung Electro-Mechanics | CL05A106MQ5NUNC | 10V 10uF X5R ±10% 0603 Multilayer Ceramic Capacitors MLCC - SMD/SMT ROHS『 』10V『 』10uF『 』X5R | C15525 | C_0402 | smt | Capacitors,Multilayer Ceramic Capacitors MLCC - SMD/SMT | $0.140 | $0.280 |  | CL05A106MQ5NUNC | It's quoted based on the LCSC part you listed in this BOM.Please confirm if the part listed in the column of *Actual Purchase Mfg Part # is the correct one you need. Package is [0402] on BOM, but we quoted as per part number and it's [0603],pls confirm. | The Actual LCSC is C15525 and the MFG Part # is CL05A106MQ5NUNC, footprint should remain 0402.
7 | C15, C18, C26, C4, C5 | 5 | Samsung Electro-Mechanics | CL05A475MP5NRNC | 10V 4.7uF X5R ±20% 0402 Multilayer Ceramic Capacitors MLCC - SMD/SMT ROHS『 』10V『 』±20%『 』4.7uF『 』X5R | C23733 | C_0402 | smt『 』SMT | Capacitors,Multilayer Ceramic Capacitors MLCC - SMD/SMT | $0.032 | $0.320 |  | CL05A475MP5NRNC
8 | C21 | 1 | Samsung Electro-Mechanics | CL05A105KA5NQNC | 25V 1uF X5R ±10% 0402 Multilayer Ceramic Capacitors MLCC - SMD/SMT ROHS『 』25V『 』±10%『 』1uF『 』X5R | C52923 | C_0402 | smt『 』SMT | Capacitors,Multilayer Ceramic Capacitors MLCC - SMD/SMT | $0.090 | $0.180 |  | CL05A105KA5NQNC
9 | C7 | 1 | Samsung Electro-Mechanics | CL05A225MQ5NSNC | 6.3V 2.2uF X5R ±20% 0402 Multilayer Ceramic Capacitors MLCC - SMD/SMT ROHS『 』10V『 』±10%『 』2.2uF『 』X7R | C2999759 | C_0402 | smt | Capacitors,Multilayer Ceramic Capacitors MLCC - SMD/SMT | $0.069 | $0.138 |  | CL05A225MQ5NSNC
10 | C8 | 1 | Samsung Electro-Mechanics | CL05B103KB5NNNC | 50V 10nF X7R ±10% 0402 Multilayer Ceramic Capacitors MLCC - SMD/SMT ROHS『 』50V『 』±10%『 』10nF『 』X7R | C15195 | C_0402 | smt『 』SMT | Capacitors,Multilayer Ceramic Capacitors MLCC - SMD/SMT | $0.011 | $0.022 |  | CL05B103KB5NNNC
11 | D1 | 1 |  | PMEG3015EJ | 30V, 1.5A ultra low Vf MEGA Schottky barrier rectifier, SOD-323F | C32798641 | SC-90 | smt |  | $0.781 | $1.562 |  | PMEG3015EJ | package is [D_SOD-323F], on BOM, but we quoted as per part number and it's [SC-90], pls confirm. | SC-90 and SOD323F are the same package, this is correct
12 | D3 | 1 | Hubei KENTO Elec | KT-0805G | Emerald 0805 LED Indication - Discrete ROHS | C2297 | D_0805 | smt『 』SMT | Optoelectronics,Light Emitting Diodes (LED) | $0.042 | $0.084 |  | KT-0805G
13 | D5, D6 | 2 | Foshan NationStar Optoelectronics | NCD0805R1 | 25mA Colorless transparent lens 67mcd~195mcd -30°C~+85°C 615nm~630nm Individual diode Red 130° 65mW 1.6V~2.6V 0805 LED Indication - Discrete ROHS | C84256 | D_0805 | smt『 』SMT | Optoelectronics,Light Emitting Diodes (LED) | $0.020 | $0.080 |  | NCD0805R1
14 | MISO1, MISO2, MOSI1, MOSI2, SCK1, SCK2 | 6 |  | 5019 | test point | C238131 | TestPoint_Keystone_5019_Miniature | smt |  | $0.486 | $5.832 |  | 5019 | It's quoted based on the LCSC part you listed in this BOM.Please confirm if the part listed in the column of *Actual Purchase Mfg Part # is the correct one you need. | 5019 is correct
15 | P1 | 1 |  | MC-311D | USB Type-C Plug connector | C136423 | USB-C | smt |  | $0.786 | $1.572 |  | MC-311D | It's quoted based on the LCSC part you listed in this BOM.Please confirm if the part listed in the column of *Actual Purchase Mfg Part # is the correct one you need. | MC-311D is correct
16 | Q2, Q3 | 2 | Alpha & Omega Semicon | AO3400A | 30V 5.7A 26.5mΩ@10V,5.7A 1.4W 1.5V@250uA 1 N-Channel SOT-23-3L MOSFETs ROHS『 』1 N-channel | C20917 | Q_SOT-23 | smt『 』SMT | Transistors,MOSFETs | $0.125 | $0.500 |  | AO3400A
17 | R1, R10, R12, R15, R2, R3, R4, R7, R9 | 9 | UNI-ROYAL(Uniroyal Elec) | 0402WGF5101TCE | 62.5mW Thick Film Resistors 50V ±100ppm/°C ±1% 5.1kΩ 0402 Chip Resistor - Surface Mount ROHS『 』±1%『 』±100ppm/°C『 』Thick Film Resistors | C25905 | R_0402 | tht『 』SMT | Resistors,Chip Resistor - Surface Mount | $0.004 | $0.072 |  | 0402WGF5101TCE
18 | R11 | 1 | UNI-ROYAL(Uniroyal Elec) | 0402WGF2000TCE | 62.5mW Thick Film Resistors 50V ±100ppm/°C ±1% 200Ω 0402 Chip Resistor - Surface Mount ROHS『 』±1%『 』±100ppm/°C『 』Thick Film Resistors | C25087 | R_0402 | tht『 』SMT | Resistors,Chip Resistor - Surface Mount | $0.008 | $0.016 |  | 0402WGF2000TCE
19 | R13, R5 | 2 | UNI-ROYAL(Uniroyal Elec) | 0603WAF750JT5E | 100mW Thick Film Resistors 75V ±1% ±200ppm/°C 75Ω 0603 Chip Resistor - Surface Mount ROHS『 』±1%『 』±200ppm/°C『 』Thick Film Resistors | C4275 | R_0603 | smt『 』SMT | Resistors,Chip Resistor - Surface Mount | $0.010 | $0.040 |  | 0603WAF750JT5E
20 | R14, R6 | 2 | UNI-ROYAL(Uniroyal Elec) | 0402WGF220JTCE | 62.5mW Thick Film Resistors 50V ±1% ±100ppm/°C 22Ω 0402 Chip Resistor - Surface Mount ROHS『 』±1%『 』±100ppm/°C『 』Thick Film Resistors | C25092 | R_0402 | tht『 』SMT | Resistors,Chip Resistor - Surface Mount | $0.012 | $0.048 |  | 0402WGF220JTCE
21 | RESET | 1 |  | TS1101S-4.5x4.5x5.5FSS |  | C49274267 | SW-SMD_4P-L4.5-W4.5-P3.15-LS7.5-TL | smt |  |  |  |  | TS1101S-4.5x4.5x5.5FSS | It has multiple suffixes, please provide the complete model number | LCSC is C49274267, MFG Part is TS1101S-4.5x4.5x5.5FSS
22 | SWD, UART1 | 2 |  | PZ200V-11-04P | Generic connector, single row, 01x04, script generated | C541858 | PinHeader_1x04_P2.00mm_Vertical | tht |  | $0.039 | $0.156 |  | PZ200V-11-04P | It's quoted based on the LCSC part you listed in this BOM.Please confirm if the part listed in the column of *Actual Purchase Mfg Part # is the correct one you need. | PZ200V-11-04P is correct
23 | U1 | 1 |  |  |  | C2655099 | LGA-14_L3.0-W2.5-P0.50-TL | smt |  | $2.747 | $5.494
24 | U2 | 1 |  | W25Q16JVSSIQ | 16Mbit / 2MiB Serial Flash Memory, Standard/Dual/Quad SPI, 2.7-3.6V, SOIC-8 (208 mil) | C131025 | SOIC-8_5.3x5.3mm_P1.27mm | smt |  | $1.086 | $2.172 |  | W25Q16JVSSIQ | It's quoted based on the LCSC part you listed in this BOM.Please confirm if the part listed in the column of *Actual Purchase Mfg Part # is the correct one you need. | W25Q16JVSSIQ is correct
25 | U3 | 1 |  |  | Absolute Barometric Pressure Sensor, LGA-8 | C83291 | Bosch_LGA-8_2x2.5mm_P0.65mm_ClockwisePinNumbering | smt |  | $6.907 | $13.814
26 | U5 | 1 | ST(意法半导体) | STM32F411CEU6 | CPU Core:ARM-M4 CPU Maximum Speed:100MHz Program Storage Size:512KB Program Memory Type:FLASH Number of I/O:36 ADC (Bit):12bit Low Voltage Detection Threshold:1.7V~3.6V Low Voltage Detection Threshold:1.7V~3.6V Application Area:-『 』带DSP和FPU的高性能基本型系列ARM Cortex-M4 MCU，具有512 KB Flash、100 MHz CPU和ART加速器 | C60420 | QFN-48-1EP_7x7mm_P0.5mm_EP5.6x5.6mm | smt |  | $1.986 | $3.972 |  | STM32F411CEU6
27 | U6 | 1 |  |  | L86 is an ultra-compact GNSS POT _Patch on Top_ module with an embedded 18.4mm × 18.4mm × 4.0mm patch antenna and utilizes the MediaTek new generation GNSS chipset MT3333 that achieves the perfect performance |  | XCVR_L86-M33『 』None | smt |  | $7.544 | $15.088
28 | U7 | 1 | G-NiceRF(思为无线) | lora1276-C1-915MHz | Frequency:915MHz Output Power:20dBm Output Power:20dBm Interface Type:SPI Modulation System:LoRa；GFSK；FSK Voltage - Supply:3.3V Voltage - Supply:3.3V Receive Current:10.8mA Send Current:120mA Sensitivity:-139dBm Sensitivity:-139dBm Operating Temperature『 』915MHz无线模块 | C3001531 | COMM-SMD_LORA1276-C1-915MHZ | tht |  | $9.351 | $18.702 |  | lora1276-C1-915MHz
29 | U9 | 1 |  | AP7361C-33E-13 | 1A Low Dropout regulator, positive, 3.3V fixed output, SOT-223 | C500795 | SOT-223-3_TabPin2 | smt |  | $0.163 | $0.326 |  | AP7361C-33E-13 | It's quoted based on the LCSC part you listed in this BOM.Please confirm if the part listed in the column of *Actual Purchase Mfg Part # is the correct one you need. | AP7361C-33E-13 is correct
30 | X1 | 1 |  | SX2B12.000F1010F30 | 12MHz Surface Mount Crystal 20pF ±10ppm ±20ppm SMD3225-4P Crystals ROHS『 』Surface Mount Crystal | C7301971 | CRYSTAL-SMD_4P-L3.2-W2.5-BL | smt |  | $0.090 | $0.180 |  | SX2B12.000F1010F30 | The correct package for the listed Part Number [X322512MSB4SI] is indeed [3225_4P], not [CRYSTAL-SMD,_4P-L3.2-W2.5-BL].Please confirm. | The corrected package is SMD2520-4P, MFG part is SX2B12.000F1010F30 and LCSC is C7301971
 |  |  |  |  |  |  |  |  |  | Component Cost | $72.41

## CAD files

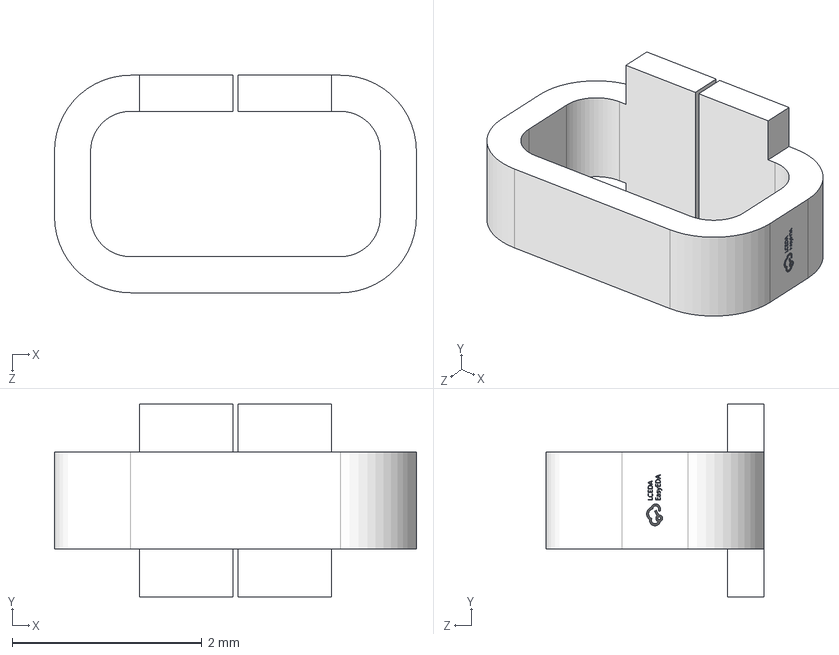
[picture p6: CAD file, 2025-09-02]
KiCad/Connectors&Switches/5019/CONN-SMD_5019.step
3.81 x 2.03 x 2.29 mm

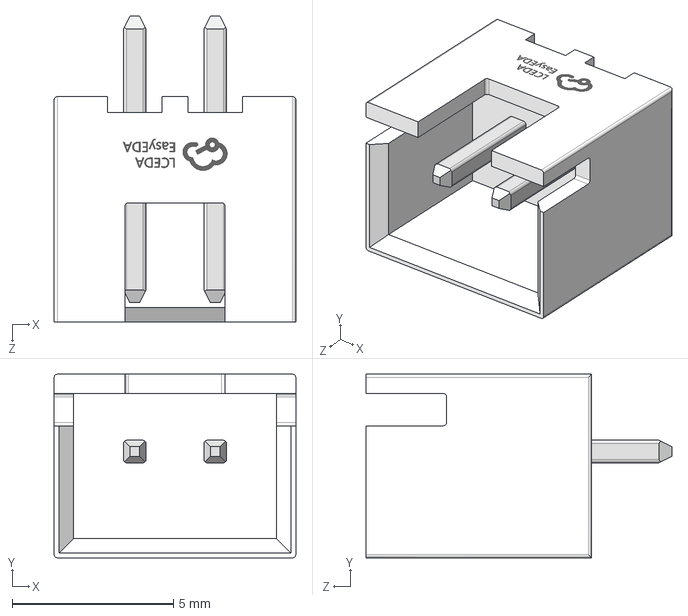
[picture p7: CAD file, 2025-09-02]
KiCad/Connectors&Switches/SMA/XH2.5-2A.step
7.50 x 5.70 x 9.50 mm

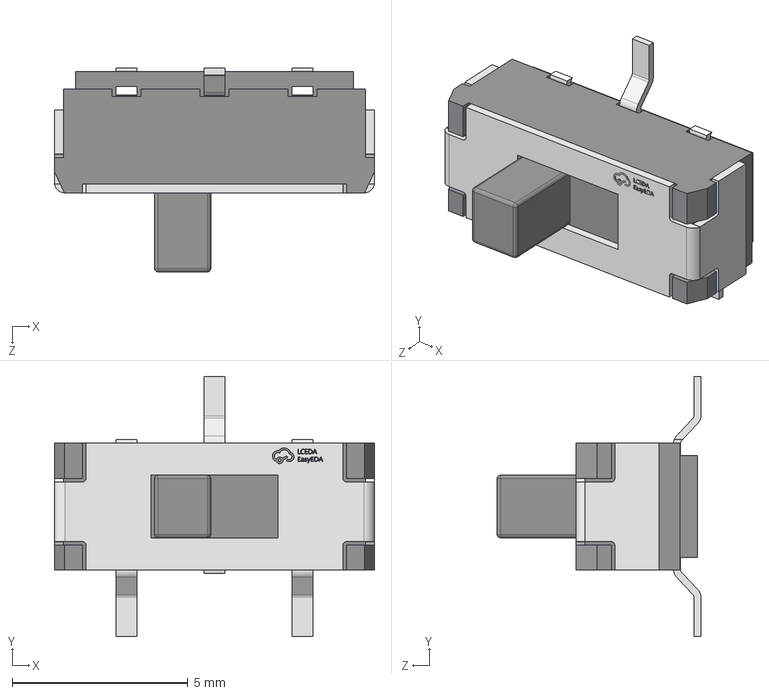
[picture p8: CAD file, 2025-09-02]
KiCad/Connectors&Switches/SW-SHOUHAN_MST-22D18G23J_C2875122/SW-SMD_SHOUHAN_MST-22D18G23J_C2875122.step
9.10 x 7.40 x 5.80 mm

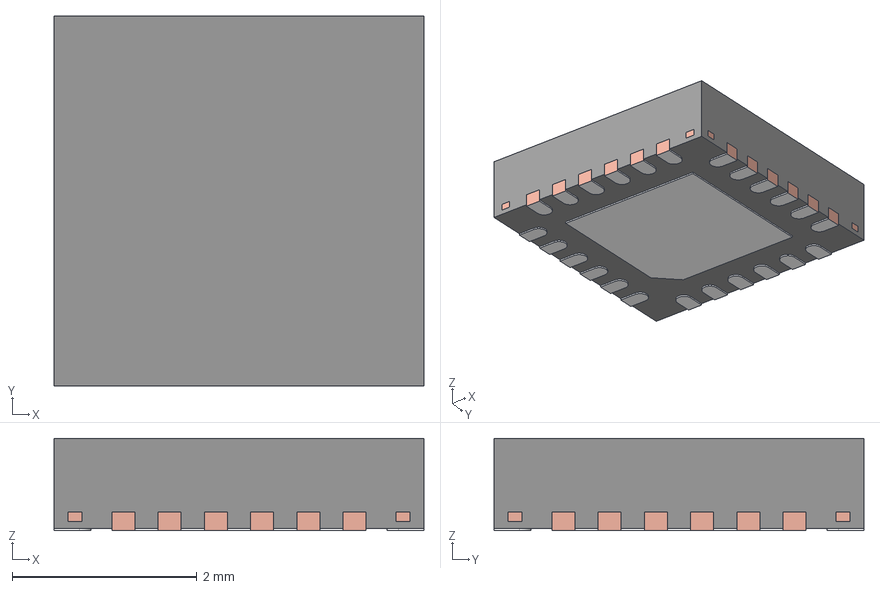
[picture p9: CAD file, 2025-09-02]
KiCad/ESC_Board/DRV3800/ul_DRV8300DRGER/RGE0024B.stp
4.00 x 4.00 x 1.00 mm
BODY-QFN
FRAME-RGE0024B
PIN1-ID

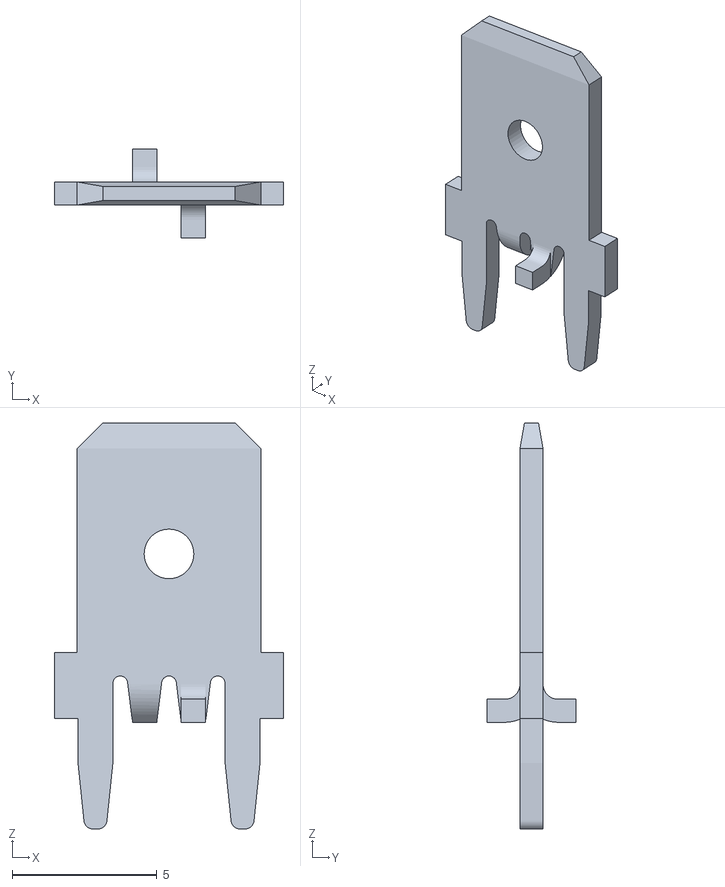
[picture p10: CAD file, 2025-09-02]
KiCad/ESC_Board/Spade/c-63824-1-ad-3d.stl
7.92 x 3.09 x 14.0

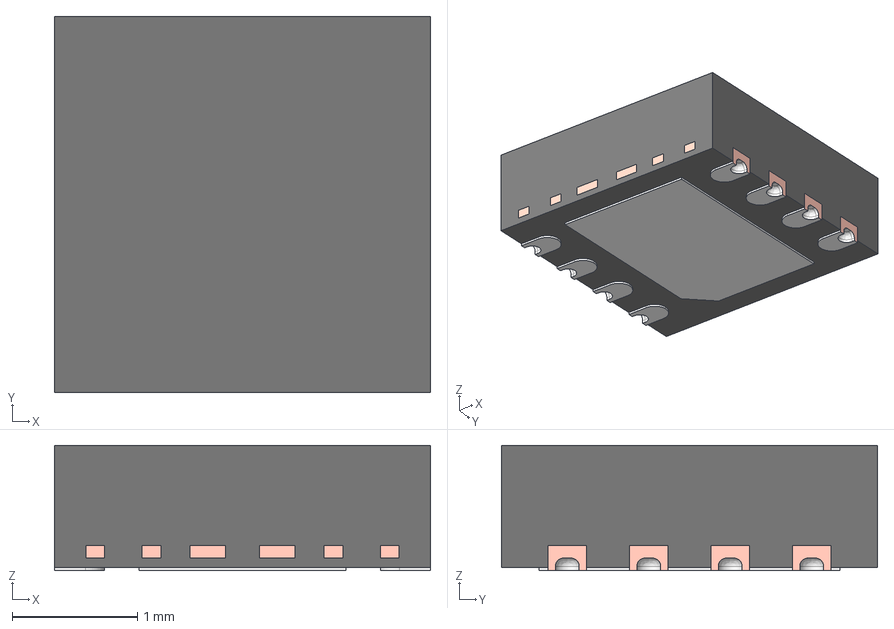
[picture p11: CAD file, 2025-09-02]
KiCad/ESC_Board/TLV765501/DRB0008J.stp
3.00 x 3.00 x 1.00 mm
FRAME

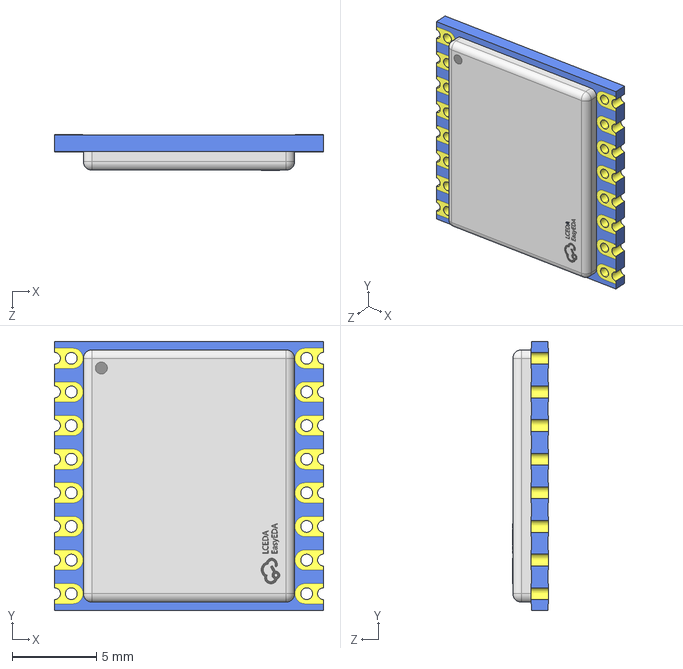
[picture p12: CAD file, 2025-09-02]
KiCad/ICs/G-NiceRF lora1276-C1-915MHz/COMM-SMD_LORA1276-C1-915MHZ.step
16.0 x 16.0 x 2.12 mm

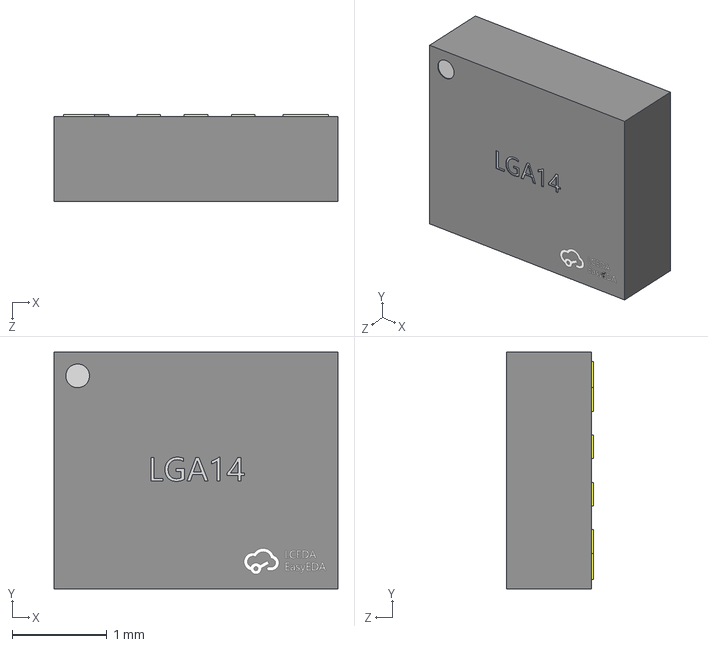
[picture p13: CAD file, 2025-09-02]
KiCad/ICs/ICM-42605/LGA-14_L2.5-W3.0-H0.9-P0.50.step
3.00 x 2.50 x 0.921 mm

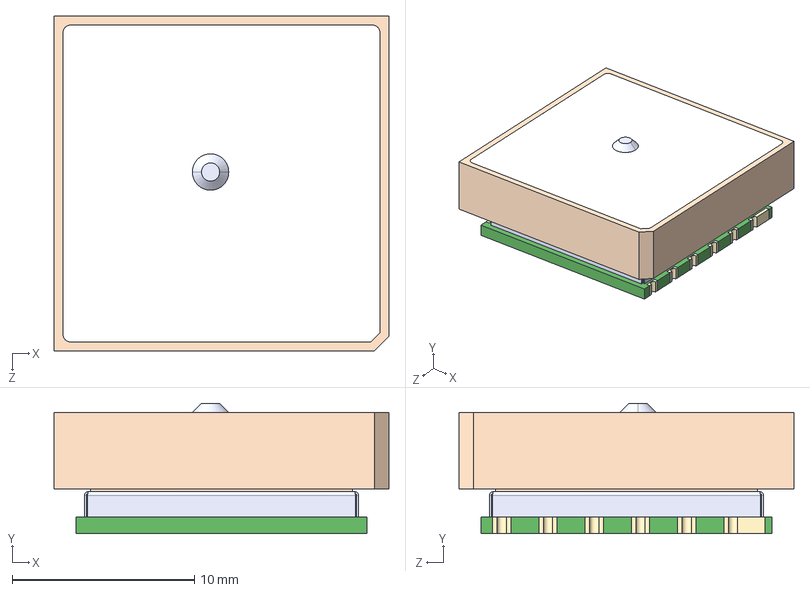
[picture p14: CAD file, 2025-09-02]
KiCad/ICs/L86/L86-M33.step
18.4 x 7.15 x 18.4 mm

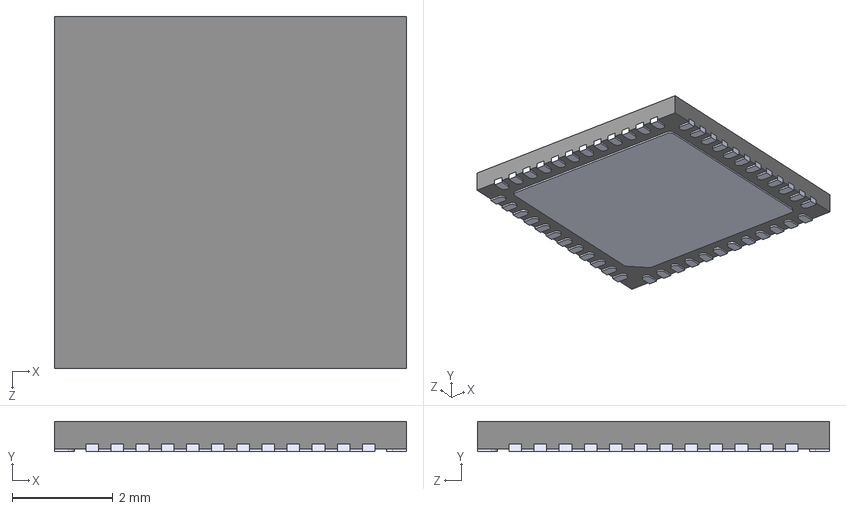
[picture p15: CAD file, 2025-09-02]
KiCad/ICs/STM32/STM32F411CEU6--3DModel-STEP-56544.STEP
7.00 x 0.6 x 7.00 mm

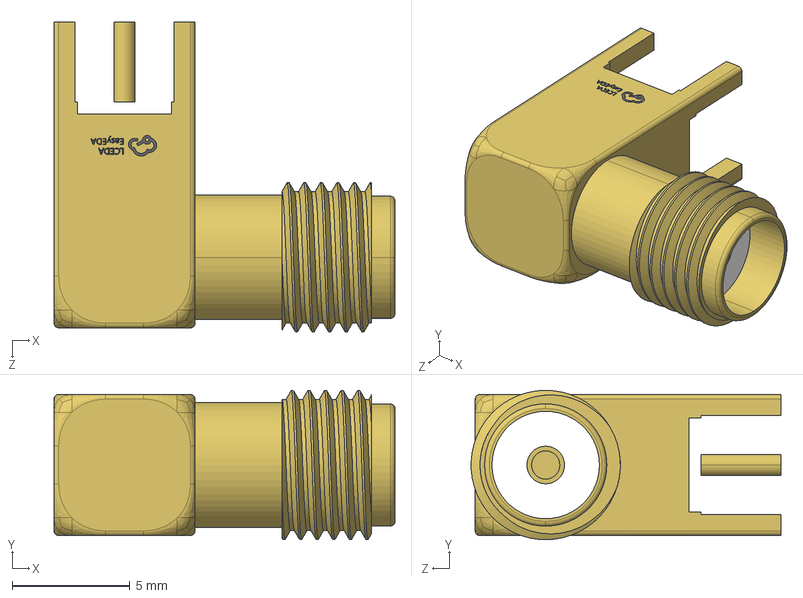
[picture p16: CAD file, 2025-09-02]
KiCad/Connectors&Switches/SMA/SMA-TH_5P-L14.5-W6.0-H9.6_BWSMA-KWE-Z001.step
14.5 x 6.35 x 13.2 mm

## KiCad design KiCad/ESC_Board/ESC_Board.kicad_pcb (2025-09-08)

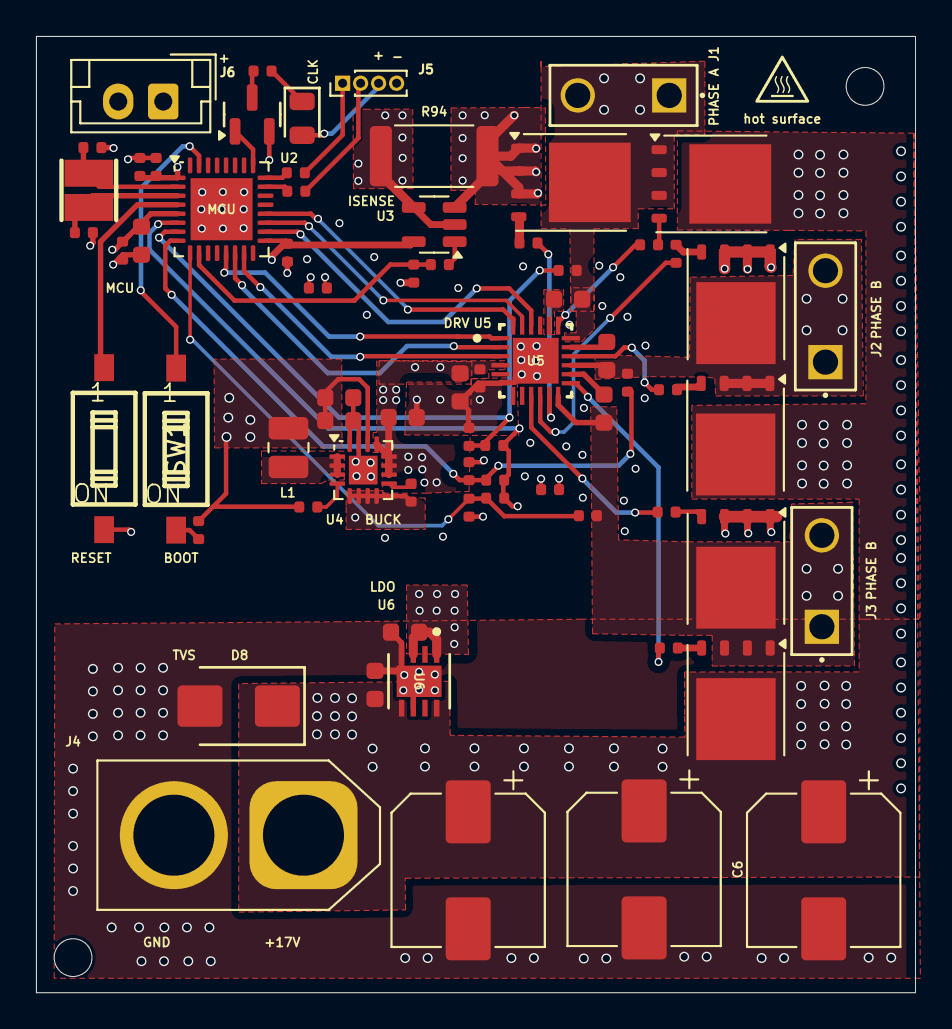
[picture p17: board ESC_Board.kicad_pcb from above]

Board: 4 copper layers, 48.8 x 53.1 mm, 70 parts (0 on the bottom side), 50 nets.

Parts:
C1, C7, C9, C16, C56, C58: 100nF; C_0402
C5, C6, C8: 100uF; CP_Elec_8x10
C10: 4.7uF; C_0402
C11, C15, C21, C53, C54: 10uF; C_0603
C12: 10nF; C_0402
C13: 3.3nF; C_0402
C20, C23, C24, C25, C26: 1uF; C_0603
C52, C55: 22pF; C_0402
D1: Red; D_0805
D8: SMBJ18A; D_SMB
J1, J2, J3: 63824-1; TRM2_63824-1_TEC
J4: Conn_01x02_Pin; AMASS_XT60-F_1x02_P7.20mm_Vertical
J5: Conn_01x04_Pin; PinHeader_1x04_P1.00mm_Vertical
J6: Conn_01x02_Pin; JST_EH_B2B-EH-A_1x02_P2.50mm_Vertical
L1: L; L_1008_2520Metric
Q1: AO3400A; Q_SOT-23
Q3, Q4, Q5, Q7, Q8: SIR182DP; TDSON-8-1
Q6: SIR182Dp; TDSON-8-1
R1, R5: 100Ω; R_0402
R2, R13, R23, R26: 1kΩ; R_0402
R3: 75Ω; R_0402
R7: 100kΩ; R_0402
R11, R14, R21, R22, R24, R25, R27: 10kΩ; R_0402
R15, R16, R17, R18, R19, R20: 22Ω; R_0402
R94: 3.0m; R_2512_6332Metric
SW1, SW2: SW_SPST; SW-SMD_2P-L3.5-W6.2-P2.54-LS9.8
U2: STM32F051K8Ux; QFN-32-1EP_5x5mm_P0.5mm_EP3.45x3.45mm
U3: INA180A1; SOT-23-5
U4: TPS62153RGTT; TQFN-16-1EP_3x3mm_P0.5mm_EP1.6x1.6mm
U5: DRV8300DRGER; RGE0024B-IPC_A
U6: TLV76601QWDRBRQ1; DRB0008J-IPC_A
Y1: Crystal_Small; OSC-SMD_2P-L3.2-W2.5

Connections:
+3.3V: C7.1, C9.1, C10.1, C12.1, C26.1, C53.2, C54.2, C56.1, D1.2, J5.3, J6.1, L1.2, R7.2, R11.1, U2.1 (VDD), U2.5 (VDDA), U2.17 (VDD), U3.5 (V+), U4.14 (VOS)
+12V: C11.1, C15.2, C16.1, C21.1, C58.1, U4.10 (AVIN), U4.11 (PVIN), U4.12 (PVIN__1), U4.13 (EN), U5.4 (GVDD), U6.1 (OUT), U6.3 (SNS)
+17V: C5.1, C6.1, C8.1, C20.1, D8.1, J4.1, Q5.5 (D), Q6.5 (D), Q7.5 (D), U6.5 (EN), U6.8 (IN)
/BEMFA: R13.1, R14.2, R21.1, U2.7 (PA1)
/BEMFB: R22.2, R23.1, R24.1, U2.8 (PA2)
/BEMFC: R25.2, R26.1, R27.1, U2.9 (PA3)
/BEMFCOMMON: R14.1, R22.1, R25.1, U2.6 (PA0)
/GHA: R15.1, U5.19 (GHA)
/GHB: R17.1, U5.16 (GHB)
/GHC: R19.1, U5.13 (GHC)
/GLA: R16.1, U5.11 (GLA)
/GLB: R18.1, U5.10 (GLB)
/GLC: R20.1, U5.9 (GLC)
/INHA: U2.18 (PA8), U5.22 (INHA)
/INHB: U2.19 (PA9), U5.23 (INHB)
/INHC: U2.20 (PA10), U5.24 (INHC)
/INLA: U2.13 (PA7), U5.1 (INLA)
/INLB: U2.14 (PB0), U5.2 (INLB)
/INLC: U2.15 (PB1), U5.3 (INLC)
/I_SENSE: C1.1, R2.2, U2.10 (PA4)
/LOW_COMMON: Q3.1 (S), Q3.2 (S), Q3.3 (S), Q4.1 (S), Q4.2 (S), Q4.3 (S), Q8.1 (S), Q8.2 (S), Q8.3 (S), R94.1, U3.3 (+)
/MOTORA: C23.2, J1.1, J1.2, Q3.5 (D), Q5.1 (S), Q5.2 (S), Q5.3 (S), R21.2, U5.18 (SHA)
/MOTORB: C24.2, J2.1, J2.2, Q4.5 (D), Q6.1 (S), Q6.2 (S), Q6.3 (S), R24.2, U5.15 (SHB)
/MOTORC: C25.2, J3.1, J3.2, Q7.1 (S), Q7.2 (S), Q7.3 (S), Q8.5 (D), R27.2, U5.12 (SHC)
/SWCLK: J5.1, R5.2
/SWDIO: J5.2, R1.2
GND: C1.2, C5.2, C6.2, C7.2, C8.2, C9.2, C10.2, C11.2, C12.2, C13.1, C15.1, C16.2, C20.2, C21.2, C26.2, C52.2, C53.1, C54.1, C55.2, C56.2, C58.2, D8.2, J4.2, J5.4, J6.2, Q1.2 (S), R13.2, R23.2, R26.2, R94.2, SW1.2 (B), U2.33 (VSS), U3.2 (GND), U3.4 (-), U4.5 (FB), U4.6 (AGND), U4.7 (FSW), U4.8 (DEF), U4.15 (PGND), U4.16 (PGND__1), U4.17 (EP), U5.6 (GND), U5.25 (PowerPAD), U6.4 (GND), U6.6 (GND), U6.9 (Thermal_Pad)
unnamed: D1.1, R3.2
unnamed: Q1.3 (D), R3.1
unnamed: Q1.1 (G), U2.25 (PA15)
unnamed: Q3.4 (G), R16.2
unnamed: Q4.4 (G), R18.2
unnamed: Q5.4 (G), R15.2
unnamed: Q6.4 (G), R17.2
unnamed: Q7.4 (G), R19.2
unnamed: Q8.4 (G), R20.2
unnamed: R2.1, U3.1
unnamed: SW1.1 (A), U2.4 (NRST)
unnamed: SW2.1 (A), U2.31 (BOOT0)
unnamed: R11.2, SW2.2 (B)
unnamed: R1.1, U2.23 (PA13)
unnamed: R5.1, U2.24 (PA14)
unnamed: C55.1, U2.2 (PF0), Y1.1
unnamed: C52.1, U2.3 (PF1), Y1.2
unnamed: R7.1, U4.4 (PG)
unnamed: C13.2, U4.9 (SS-TR)
unnamed: L1.1, U4.1 (SW), U4.2 (SW__1), U4.3 (SW__2)
unnamed: C23.1, U5.20 (BSTA)
unnamed: C24.1, U5.17 (BSTB)
unnamed: C25.1, U5.14 (BSTC)

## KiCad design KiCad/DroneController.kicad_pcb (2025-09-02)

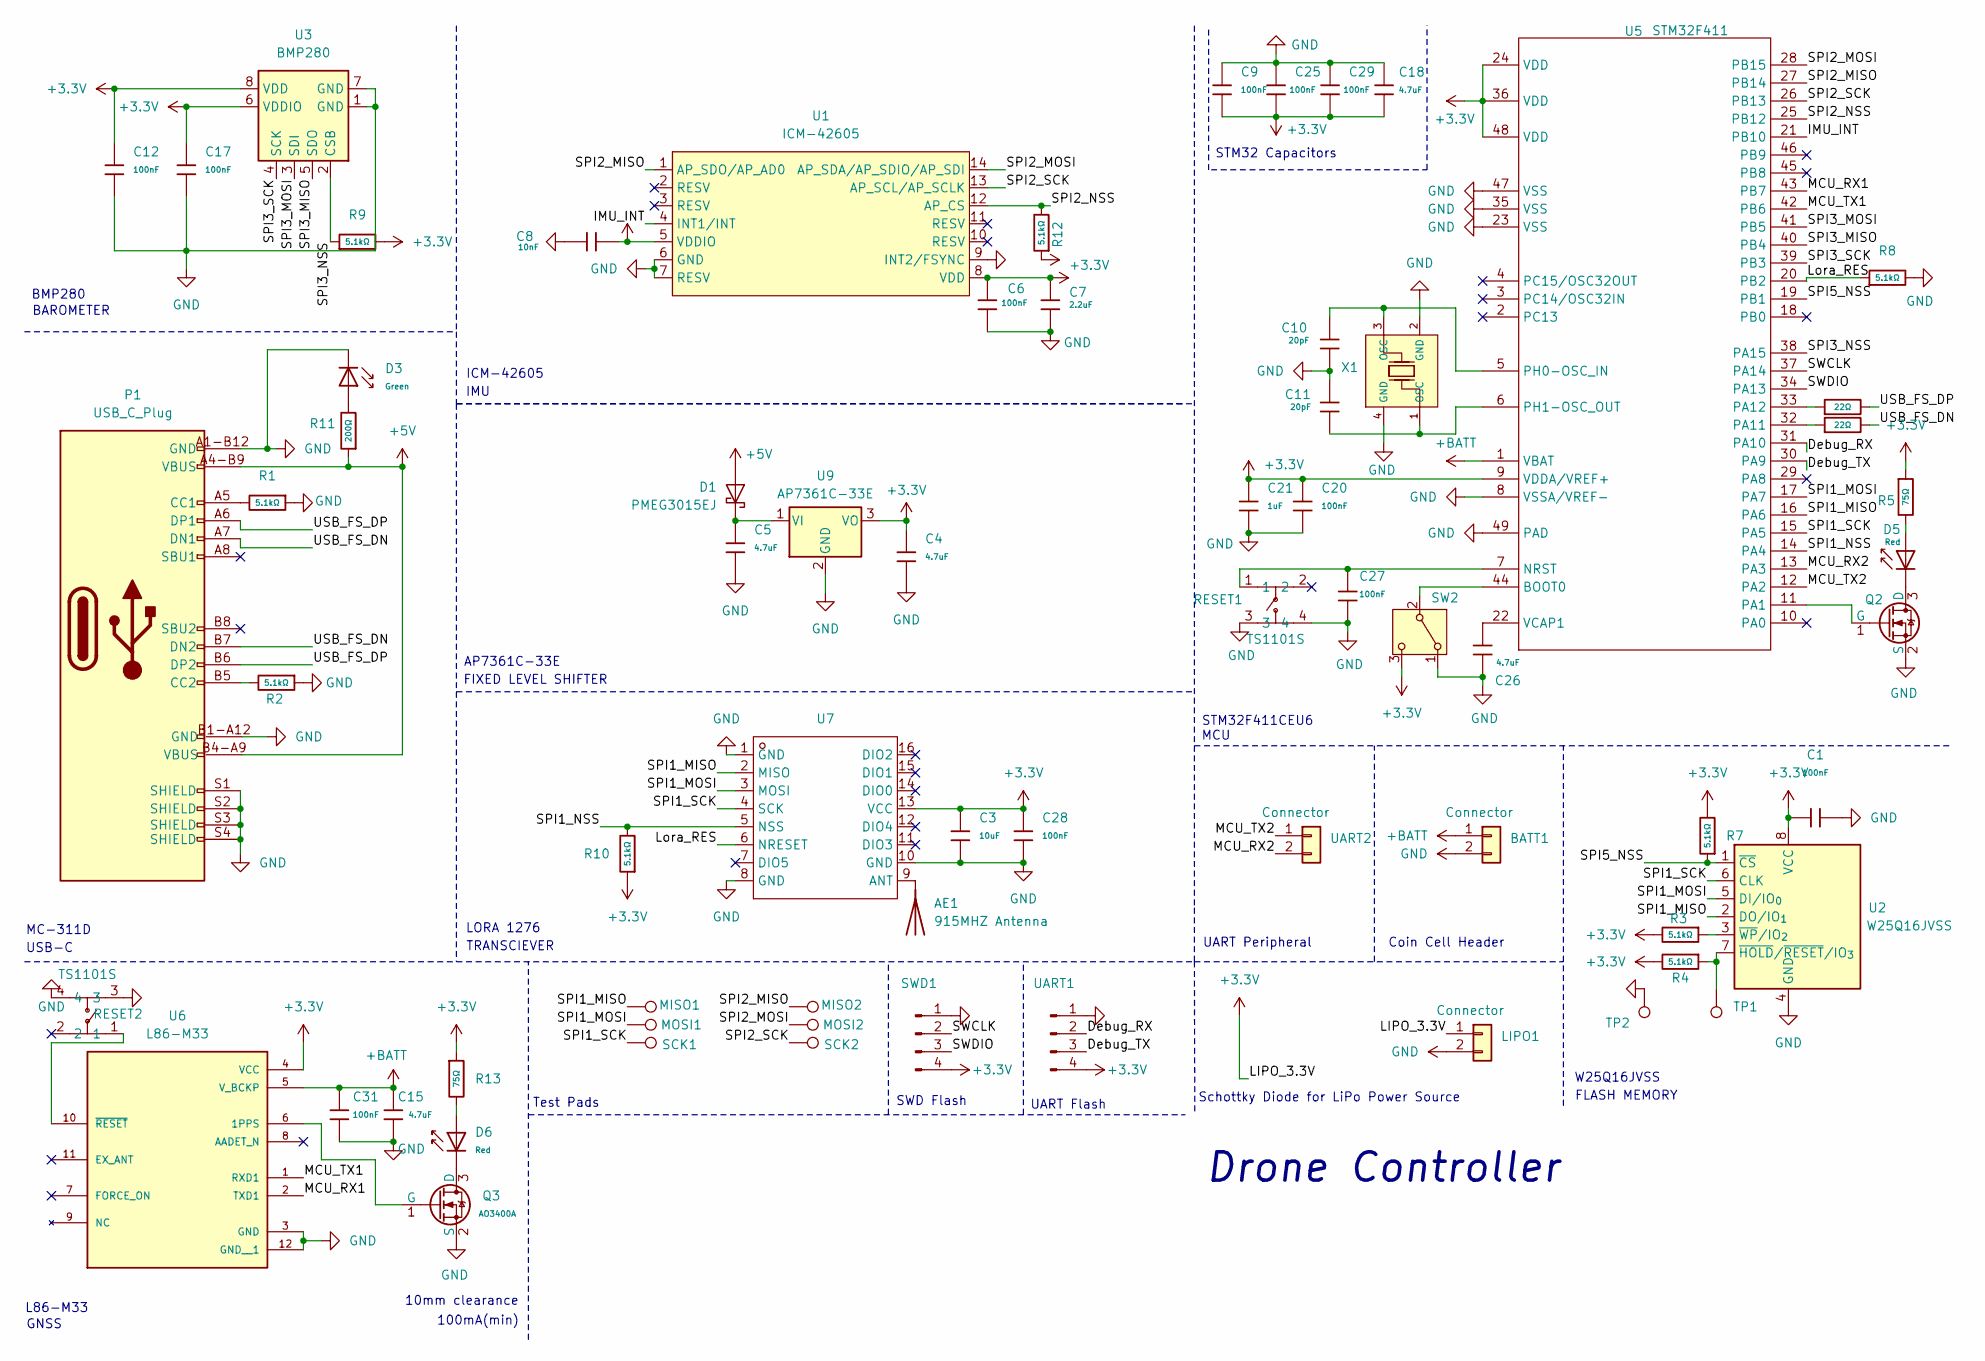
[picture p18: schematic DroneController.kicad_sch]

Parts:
AE1: 915MHZ Antenna; SMA_BAT_Wireless_BWSMA-KWE-Z001; LCSC Part Number C496551
BATT1: Connector; CONN-TH_B2B-XH-A-LF-SN; LCSC Part Number C158012
C1, C6, C9, C12, C17, C20, C25, C27, C28, C29, C31: 100nF; C_0402; Voltage Rated 16V; Tolerance ±10%; Part CL05B104KO5NNNC; LCSC Part Number C1525
C3: 10uF; C_0402; Voltage Rated 6.3V; Tolerance ±20%; Part CL05A106MQ5NUNC; LCSC C15525
C4, C5, C15, C18, C26: 4.7uF; C_0402; Voltage Rated 10V; Tolerance ±20%; Part CL05A475MP5NRNC; LCSC Part Number C23733
C7: 2.2uF; C_0402; Voltage Rated 10V; Tolerance ±10%; Part CL05A225MQ5NSNC; LCSC Part Number C2999759
C8: 10nF; C_0402; Voltage Rated 50V; Tolerance ±10%; Part CL05B103KB5NNNC; LCSC Part Number C15195
C10, C11: 20pF; C_0402; Voltage Rated 50V; Tolerance ±5%; Part 0402CG200J500NT; LCSC Part Number C1554
C21: 1uF; C_0402; Voltage Rated 25V; Tolerance ±10%; Part CL05A105KA5NQNC; LCSC Part Number C52923
D1: PMEG3015EJ; D_SOD-323F; LCSC Part Number C32798641
D3: Green; D_0805; Part KT-0805G; LCSC Part Number C2297
D5, D6: Red; D_0805; Forward Voltage (VF) 1.6V~2.6V; Part NCD0805R1; LCSC Part Number C84256
LIPO1: Connector; CONN-TH_B2B-XH-A-LF-SN; LCSC Part Number C158012
MISO1, MISO2: TestPoint; TestPoint_Keystone_5019_Miniature; LCSC Part Number C238131
MOSI1, MOSI2: TestPoint; TestPoint_Keystone_5019_Miniature; LCSC Part Number C238131
P1: USB_C_Plug; USB-C; LCSC Part Number C136423
Q2, Q3: AO3400A; Q_SOT-23; Part AO3400A; LCSC Part Number C20917
R1, R2, R3, R4, R7, R9, R10, R12: 5.1kΩ; R_0402; Overload Voltage (Max) 50V; Tolerance ±1%; Part 0402WGF5101TCE; LCSC Part Number C25905
R5, R13: 75Ω; R_0603; Overload Voltage (Max) 75V; Tolerance ±1%; Part 0603WAF750JT5E; LCSC Part Number C4275
R6, R14: 22Ω; R_0402; Overload Voltage (Max) 50V; Tolerance ±1%; Part 0402WGF220JTCE; LCSC Part Number C25092
R8: 5.1kΩ; R_0402; Overload Voltage (Max) 50V; Tolerance ±1%; Part 0402WGF5101TCE; LCSC C25905
R11: 200Ω; R_0402; Overload Voltage (Max) 50V; Tolerance ±1%; Part 0402WGF2000TCE; LCSC Part Number C25087
RESET1, RESET2: TS1101S; SW-SMD_4P-L4.5-W4.5-P3.15-LS7.5-TL; LCSC Part Number C49274267
SCK1, SCK2: TestPoint; TestPoint_Keystone_5019_Miniature; LCSC Part Number C238131
SW2: SW_SPDT; SW-SMD_SHOUHAN_MST-22D18G23J_C2875122; LCSC Part Number C2875122
SWD1: Conn_01x04_Pin; PinHeader_1x04_P2.00mm_Vertical; LCSC Part Number C541858
TP1, TP2: TestPoint
U1: ICM-42605; LGA-14_L3.0-W2.5-P0.50-TL; LCSC Part Number C2655099
U2: W25Q16JVSS; SOIC-8_5.3x5.3mm_P1.27mm; LCSC Part Number C131025
U3: BMP280; Bosch_LGA-8_2x2.5mm_P0.65mm_ClockwisePinNumbering; LCSC Part Number C83291
U5: STM32F411; QFN-48-1EP_7x7mm_P0.5mm_EP5.6x5.6mm; LCSC Part Number C60420
U6: L86-M33; XCVR_L86-M33; Digikey Part Number 2958-L86-M33CT-ND
U7: 915MHz; COMM-SMD_LORA1276-C1-915MHZ; LCSC Part Number C3001531
U9: AP7361C-33E; SOT-223-3_TabPin2; LCSC Part Number C500795
UART1: Conn_01x04_Pin; PinHeader_1x04_P2.00mm_Vertical; LCSC Part Number C541858
UART2: Connector; CONN-TH_B2B-XH-A-LF-SN; LCSC Part Number C158012
X1: Shenzhen SCTF Elec SX2B12.000F1010F30; Crystal_SMD_2520-4Pin_2.5x2.0mm; Frequency Tolerance ±10ppm; Part X322512MSB4SI; LCSC Part Number C7301971

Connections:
+3.3V: C1.2, C3.1, C4.1, C6.2, C7.1, C8.2, C9.2, C12.1, C17.1, C18.1, C20.1, C21.1, C25.2, C28.1, C29.2, LIPO1.1, R3.2, R4.2, R5.1, R7.2, R9.2, R10.1, R12.1, R13.1, SW2.3 (C), SWD1.4, U1.5 (VDDIO), U1.8 (VDD), U2.8 (VCC), U3.6 (VDDIO), U3.8 (VDD), U5.9 (VDDA/VREF+), U5.24 (VDD), U5.36 (VDD), U5.48 (VDD), U6.4 (VCC), U7.13 (VCC), U9.3 (VO), UART1.4; also elsewhere on the board
+5V: D1.2 (A), P1.A4-B9 (VBUS), P1.B4-A9 (VBUS), R11.1
+BATT: BATT1.1, C15.1, C31.1, U5.1 (VBAT), U6.5 (V_BCKP)
/Debug_RX: U5.31 (PA10), UART1.2
/Debug_TX: U5.30 (PA9), UART1.3
/IMU_INT: U1.4 (INT1/INT), U5.21 (PB10)
/Lora_RES: R8.1, U5.20 (PB2), U7.6 (NRESET)
/MCU_RX1: U5.43 (PB7), U6.2 (TXD1)
/MCU_RX2: U5.13 (PA3), UART2.2
/MCU_TX1: U5.42 (PB6), U6.1 (RXD1)
/MCU_TX2: U5.12 (PA2), UART2.1
/SPI1_MISO: MISO1.1, U2.2 (DO/IO_{1}), U5.16 (PA6), U7.2 (MISO)
/SPI1_MOSI: MOSI1.1, U2.5 (DI/IO_{0}), U5.17 (PA7), U7.3 (MOSI)
/SPI1_NSS: R10.2, U5.14 (PA4), U7.5 (NSS)
/SPI1_SCK: SCK1.1, U2.6 (CLK), U5.15 (PA5), U7.4 (SCK)
/SPI2_MISO: MISO2.1, U1.1 (AP_SDO/AP_AD0), U5.27 (PB14)
/SPI2_MOSI: MOSI2.1, U1.14 (AP_SDA/AP_SDIO/AP_SDI), U5.28 (PB15)
/SPI2_NSS: R12.2, U1.12 (AP_CS), U5.25 (PB12)
/SPI2_SCK: SCK2.1, U1.13 (AP_SCL/AP_SCLK), U5.26 (PB13)
/SPI3_MISO: U3.5 (SDO), U5.40 (PB4)
/SPI3_MOSI: U3.3 (SDI), U5.41 (PB5)
/SPI3_NSS: R9.1, U3.2 (CSB), U5.38 (PA15)
/SPI3_SCK: U3.4 (SCK), U5.39 (PB3)
/SPI5_NSS: R7.1, U2.1 (~CS), U5.19 (PB1)
/SWCLK: SWD1.2, U5.37 (PA14)
/SWDIO: SWD1.3, U5.34 (PA13)
/USB_FS_DN: P1.A7 (DN1), P1.B7 (DN2), R6.2
/USB_FS_DP: P1.A6 (DP1), P1.B6 (DP2), R14.2
GND: BATT1.2, C1.1, C3.2, C4.2, C5.2, C6.1, C7.2, C8.1, C9.1, C10.2, C11.1, C12.2, C15.2, C17.2, C18.2, C20.2, C21.2, C25.1, C26.2, C27.2, C28.2, C29.1, C31.2, D3.1, LIPO1.2, P1.A1-B12 (GND), P1.B1-A12 (GND), P1.S1 (SHIELD), P1.S2 (SHIELD), P1.S3 (SHIELD), P1.S4 (SHIELD), Q2.2 (S), Q3.2 (S), R1.1, R2.1, R8.2, RESET1.3, RESET1.4, RESET2.3, RESET2.4, SW2.1 (A), SWD1.1, TP2.1, U1.6 (GND), U1.7 (RESV), U1.9 (INT2/FSYNC), U2.4 (GND), U3.1 (GND), U3.7 (GND), U5.8 (VSSA/VREF-), U5.23 (VSS), U5.35 (VSS), U5.47 (VSS), U5.49 (PAD), U6.3 (GND), U6.12 (GND__1), U7.1 (GND), U7.8 (GND), U7.10 (GND), U9.2 (GND), UART1.1, X1.2 (GND), X1.4 (GND); also elsewhere on the board
unnamed: AE1.1 (A), U7.9 (ANT)
unnamed: C5.1, D1.1 (K), U9.1 (VI)
unnamed: D3.2, R11.2
unnamed: D5.2, R5.2
unnamed: D6.2, R13.2
unnamed: P1.A5 (CC1), R1.2
unnamed: P1.B5 (CC2), R2.2
unnamed: D5.1, Q2.3 (D)
unnamed: Q2.1 (G), U5.11 (PA1)
unnamed: D6.1, Q3.3 (D)
unnamed: Q3.1 (G), U6.6 (1PPS)
unnamed: SW2.2 (B), U5.44 (BOOT0)
unnamed: R4.1, TP1.1, U2.7 (~HOLD/~RESET/IO_{3})
unnamed: R3.1, U2.3 (~WP/IO_{2})
unnamed: C27.1, RESET1.1, U5.7 (NRST)
unnamed: R6.1, U5.32 (PA11)
unnamed: R14.1, U5.33 (PA12)
unnamed: C10.1, U5.5 (PH0-OSC_IN), X1.3 (OSC)
unnamed: C11.2, U5.6 (PH1-OSC_OUT), X1.1 (OSC)
unnamed: C26.1, U5.22 (VCAP1)
unnamed: RESET2.1, U6.10 (~RESET)

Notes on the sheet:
TRANSCIEVER
FLASH MEMORY
STM32F411CEU6
Drone Controller
ICM-42605
UART Peripheral
Coin Cell Header
L86-M33
Schottky Diode for LiPo Power Source
Test Pads
IMU
MC-311D
SWD Flash
UART Flash
100mA(min)
AP7361C-33E
FIXED LEVEL SHIFTER
BAROMETER
USB-C
10mm clearance
BMP280
STM32 Capacitors
GNSS
MCU
W25Q16JVSS
LORA 1276

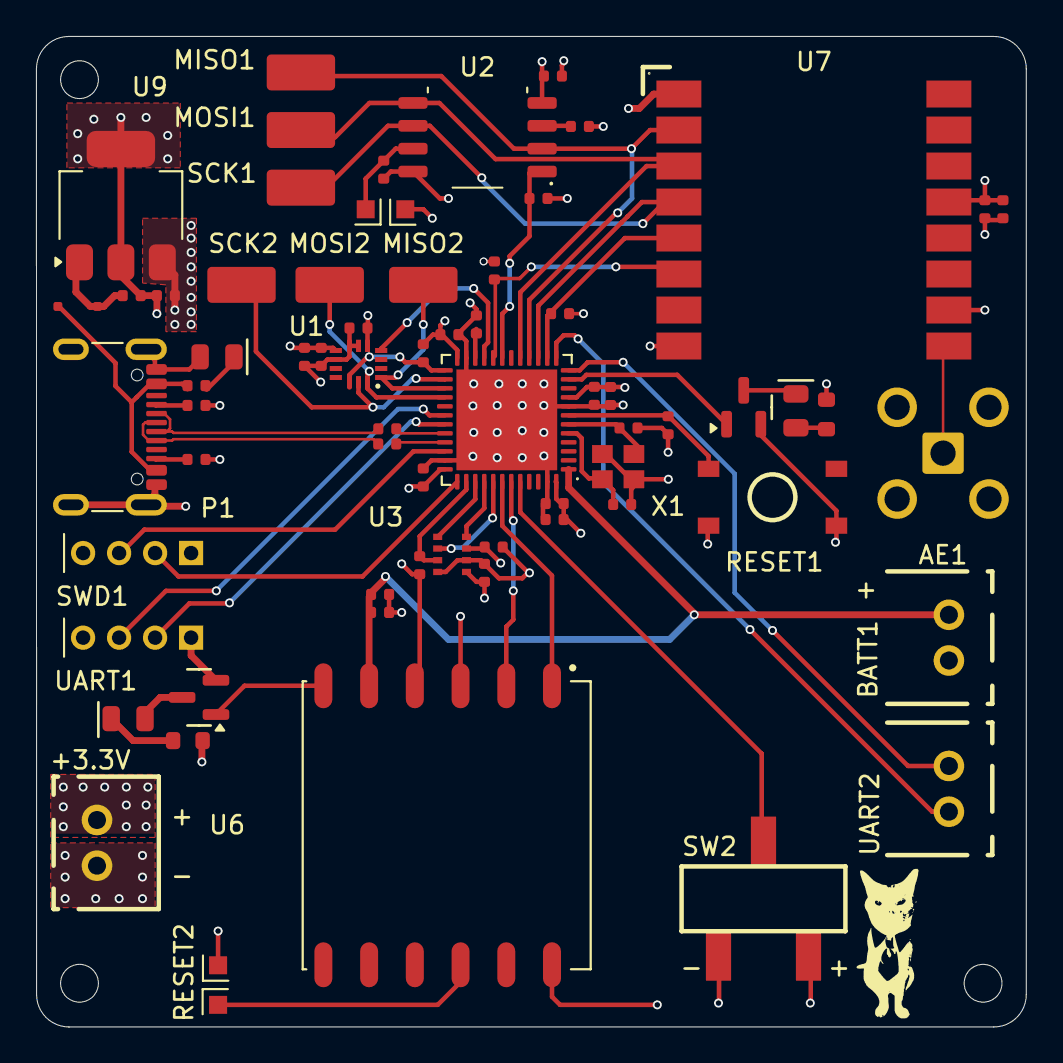
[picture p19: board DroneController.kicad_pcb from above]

Board: 4 copper layers, 55.0 x 55.0 mm, 65 parts (0 on the bottom side), 49 nets.

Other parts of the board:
+3.3V: Connector; CONN-TH_B2B-XH-A-LF-SN

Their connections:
+3.3V: +3.3V.2; also elsewhere on the board
GND: +3.3V.1; also elsewhere on the board

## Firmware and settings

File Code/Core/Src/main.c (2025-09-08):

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
/* Includes ------------------------------------------------------------------*/
#include "main.h"
#include "usb_device.h"

/* USER CODE BEGIN Includes */
#include "ICM-42605.h"
#include "BMP280.h"
#include "GPS.h"
#include <stdio.h>
#include <string.h>
#include <math.h>

#define SEA_LEVEL_PA     101325.0f

// Simple GPS test variables
volatile uint32_t uart_rx_count = 0;
volatile uint8_t last_byte = 0;

// --- IMU calibration settings ---
#define IMU_CAL_SAMPLES     512    // number of samples to average
#define IMU_CAL_SETTLE_MS   200    // small settle before sampling
#define EMA_ALPHA           0.12f  // optional smoothing (0..1). Lower = smoother

// Biases stored in RAW COUNTS (not m/s² or dps)
static float acc_bias_counts[3] = {0};
static float gyr_bias_counts[3] = {0};

// Optional EMA filtered values (in 'g' and dps)
static float ax_g_f=0, ay_g_f=0, az_g_f=0;
static float gx_dps_f=0, gy_dps_f=0, gz_dps_f=0;

/* USER CODE END Includes */

SPI_HandleTypeDef hspi1;
SPI_HandleTypeDef hspi2;
SPI_HandleTypeDef hspi3;

UART_HandleTypeDef huart1;
UART_HandleTypeDef huart2;

/* USER CODE BEGIN PV */
#define BMP280_CS_GPIO   GPIOA
#define BMP280_CS_PIN    NSS3_Pin

static BMP280_HandleTypeDef bmp;
/* USER CODE END PV */

void SystemClock_Config(void);
static void MX_GPIO_Init(void);
static void MX_SPI1_Init(void);
static void MX_SPI2_Init(void);
static void MX_SPI3_Init(void);
static void MX_USART2_UART_Init(void);
static void MX_USART1_UART_Init(void);
/* USER CODE BEGIN PFP */
static void BMP280_AppInit(void);
/* USER CODE END PFP */

/* USER CODE BEGIN 0 */
static void IMU_Calibrate(void)
{
    // Hold the board still, Z+ pointing up
    HAL_Delay(IMU_CAL_SETTLE_MS);

    int64_t sax = 0, say = 0, saz = 0;
    int64_t sgx = 0, sgy = 0, sgz = 0;
    int16_t a[3], g[3];

    for (int i = 0; i < IMU_CAL_SAMPLES; i++) {
        if (icm42605_read_accel(a) == HAL_OK) {
            sax += a[0]; say += a[1]; saz += a[2];
        }
        if (icm42605_read_gyro(g) == HAL_OK) {
            sgx += g[0]; sgy += g[1]; sgz += g[2];
        }
        HAL_Delay(2); // ~500 Hz sampling during calibration
    }

    const float invN = 1.0f / (float)IMU_CAL_SAMPLES;
    const float mean_ax = (float)sax * invN;
    const float mean_ay = (float)say * invN;
    const float mean_az = (float)saz * invN;
    const float mean_gx = (float)sgx * invN;
    const float mean_gy = (float)sgy * invN;
    const float mean_gz = (float)sgz * invN;

    // Accel biases in COUNTS: zero X/Y; make Z read exactly +1g at rest
    acc_bias_counts[0] = mean_ax;
    acc_bias_counts[1] = mean_ay;
    acc_bias_counts[2] = mean_az - ACCEL_LSB_PER_G;  // assumes Z+ up

    // Gyro biases in COUNTS (should be near 0 at rest)
    gyr_bias_counts[0] = mean_gx;
    gyr_bias_counts[1] = mean_gy;
    gyr_bias_counts[2] = mean_gz;

    // Prime EMAs with first values post-cal
    ax_g_f = 0.0f; ay_g_f = 0.0f; az_g_f = 1.0f;
    gx_dps_f = gy_dps_f = gz_dps_f = 0.0f;
}

/* USER CODE END 0 */

/**
  * @brief  The application entry point.
  * @retval int
  */
/* USER CODE END 0 */

/**
  * @brief  The application entry point.
  * @retval int
  */
int main(void)
{

  /* MCU Configuration--------------------------------------------------------*/

  /* Reset of all peripherals, Initializes the Flash interface and the Systick. */
  HAL_Init();

  /* Configure the system clock */
  SystemClock_Config();

  /* Initialize all configured peripherals */
  MX_GPIO_Init();
  MX_SPI1_Init();
  MX_SPI2_Init();
  MX_SPI3_Init();
  MX_USART2_UART_Init();
  MX_USB_DEVICE_Init();
  MX_USART1_UART_Init();
  /* USER CODE BEGIN 2 */

  printf("Starting GPS and sensor test\r\n");
  // Initialize GPS module
    if (GPS_Init() == HAL_OK) {
        printf("GPS module initialized successfully\r\n");
    } else {
        printf("GPS module initialization failed\r\n");
    }
  // Make sure BMP280 CS idles HIGH before first SPI transaction
  HAL_GPIO_WritePin(BMP280_CS_GPIO, BMP280_CS_PIN, GPIO_PIN_SET);

  // Initialize/configure BMP280
  BMP280_AppInit();

  printf("USB CDC up!\n");

  uint8_t id[3];
  if (W25_ReadJEDEC(id) == HAL_OK){
     printf("JEDEC: %02X %02X %02X\r\n", id[0], id[1], id[2]);
     HAL_GPIO_TogglePin (GPIOA, LED_Pin);
     HAL_Delay(1000);
     HAL_GPIO_TogglePin (GPIOA, LED_Pin);
    } else {
     printf("JEDEC read failed\r\n");
    }


  uint8_t whoami;
  HAL_StatusTypeDef whoami_test;

  whoami_test = icm42605_read_reg(0,0x75, &whoami);
  if (whoami_test == HAL_OK) {
      if (whoami == 0x42) {
          printf("Confirmed ICM WHOAMI: 0x%02X\r\n", whoami);
          HAL_Delay(500);
          HAL_GPIO_TogglePin(GPIOA, LED_Pin);
          HAL_Delay(1000);
          HAL_GPIO_TogglePin(GPIOA, LED_Pin);
      } else {
          printf("ICM WHOAMI mismatch: got 0x%02X (expected 0x42)\r\n", whoami);
      }
  } else {
      printf("Failed to read WHOAMI register (status: %d)\r\n", whoami_test);
  }

  // Reset chip
  icm42605_reset();

  // Configure accelerometer and gyro
  icm42605_config_accel(ACCEL_FS_2G, ACCEL_ODR_1KHZ);
  icm42605_config_gyro(GYRO_FS_2000DPS, GYRO_ODR_1KHZ);
  /* USER CODE END 2 */

  /* Infinite loop */
  /* USER CODE BEGIN WHILE */
  printf("Calibrating IMU... keep board still for ~1s\r\n");
  IMU_Calibrate();
  printf("Accel bias (cts): [%.1f, %.1f, %.1f], Gyro bias (cts): [%.1f, %.1f, %.1f]\r\n",
         acc_bias_counts[0], acc_bias_counts[1], acc_bias_counts[2],
         gyr_bias_counts[0], gyr_bias_counts[1], gyr_bias_counts[2]);
  int16_t accel[3];
  int16_t gyro[3];

  float ax_ms2, ay_ms2, az_ms2;
  float gx_dps, gy_dps, gz_dps;
  float pitch_deg, roll_deg;

  uint32_t next_bmp = HAL_GetTick();   // 5 Hz BMP280
  uint32_t next_gps = HAL_GetTick();   // 1 Hz GPS

  printf("Enter while(1)\r\n");
  extern void sx1276_min_demo(void);
  sx1276_min_demo();

  while (1)
   {

	  // Add this code to your main while loop for GPS simulation
	  // GPS Simulation (1 Hz) - replace your existing GPS processing section
	  if ((int32_t)(HAL_GetTick() - next_gps) >= 0) {
	      next_gps += 1000;

	      // Simulate GPS fix data with realistic changing values
	      static float sim_lat = 43.6532;      // Starting latitude (Toronto, Ontario)
	      static float sim_lon = -79.3832;     // Starting longitude (Toronto, Ontario)
	      static float sim_alt = 10.0;         // Starting altitude in meters
	      static float sim_speed = 0.0;        // Starting speed in knots
	      static float sim_course = 0.0;       // Starting course in degrees
	      static uint8_t sim_sats = 8;         // Number of satellites
	      static uint32_t sim_time_s = 0;      // Elapsed seconds for time simulation
	      static bool gps_fixed = false;
	      static uint32_t startup_counter = 0;

	      startup_counter++;

	      // Simulate GPS startup sequence (takes ~10 seconds to get fix)
	      if (startup_counter < 10) {
	          printf("[GPS] Searching for satellites... (%d/4 satellites)\r\n", startup_counter / 3);
	      } else if (!gps_fixed) {
	          gps_fixed = true;
	          printf("[GPS] GPS Fix acquired! Starting navigation...\r\n");
	      } else {
	          // Simulate realistic GPS movement and variations
	          sim_time_s++;

	          // Simulate slow movement (walking pace)
	          static float movement_angle = 0.0;
	          movement_angle += 0.05f;  // Slow rotation

	          // Add small realistic variations to position (GPS drift simulation)
	          sim_lat += (sinf(movement_angle * 0.1f) * 0.000005f);  // ~0.5m variation
	          sim_lon += (cosf(movement_angle * 0.1f) * 0.000005f);  // ~0.5m variation

	          // Simulate altitude changes (small variations)
	          sim_alt += sinf(movement_angle * 0.02f) * 0.5f + (rand() % 20 - 10) * 0.1f;
	          if (sim_alt < 0) sim_alt = 0;

	          // Simulate speed (walking/stationary with variations)
	          sim_speed = 0.5f + sinf(movement_angle * 0.3f) * 0.3f + (rand() % 10) * 0.05f;
	          if (sim_speed < 0) sim_speed = 0;

	          // Simulate course changes
	          sim_course = fmodf(sim_course + (rand() % 10 - 5) * 2.0f, 360.0f);
	          if (sim_course < 0) sim_course += 360.0f;

	          // Simulate satellite count variations (7-12 satellites)
	          if (sim_time_s % 10 == 0) {
	              sim_sats = 7 + (rand() % 6);
	          }

	          // Calculate time (simulate UTC time)
	          uint8_t hours = (sim_time_s / 3600) % 24;
	          uint8_t minutes = (sim_time_s / 60) % 60;
	          uint8_t seconds = sim_time_s % 60;

	          // Simulate date (fixed date for demo)
	          uint8_t day = 7;
	          uint8_t month = 9;
	          uint16_t year = 2025;

	          // Display GPS information
	          printf("[GPS] Lat: %.6f° Lon: %.6f°\r\n", sim_lat, sim_lon);
	          printf("[GPS] Satellites: %d Quality: DGPS\r\n", sim_sats);

	          // Simulate some raw NMEA-like output every few seconds
	          if (sim_time_s % 5 == 0) {
	              printf("[GPS RAW] $GPRMC,%02d%02d%02d.00,A,%.4f,N,%.4f,W,%.1f,%.1f,%02d%02d%02d,,,A*XX\r\n",
	                     hours, minutes, seconds,
	                     sim_lat, -sim_lon, sim_speed, sim_course,
	                     day, month, year % 100);
	          }

	          // Simulate HDOP and signal quality variations
	          if (sim_time_s % 3 == 0) {
	              float hdop = 1.0f + (rand() % 50) * 0.02f; // HDOP between 1.0-2.0
	              printf("[GPS] HDOP: %.2f Signal Quality: %s\r\n",
	                     hdop, (hdop < 1.5f) ? "Excellent" : (hdop < 2.0f) ? "Good" : "Fair");
	          }

	          // Simulate antenna status occasionally
	          if (sim_time_s % 15 == 0) {
	              printf("[GPS] Antenna Status: OK (Internal patch antenna)\r\n");
	          }
	      }

	      // Debug counter for simulation
	      static uint32_t debug_counter = 0;
	      debug_counter++;
	      if (debug_counter >= 30) {  // Every 30 seconds
	          debug_counter = 0;
	          printf("[GPS DEBUG] Simulation running for %lu seconds\r\n", sim_time_s);
	          printf("[GPS DEBUG] Position accuracy: ±3m, Time accuracy: ±50ms\r\n");
	      }
	  }

    // --- Read and convert accelerometer ---
     // --- Read raw accel/gyro ---
     if (icm42605_read_accel(accel) == HAL_OK) {
         // Bias-correct in COUNTS
         const float ax_c = (float)accel[0] - acc_bias_counts[0];
         const float ay_c = (float)accel[1] - acc_bias_counts[1];
         const float az_c = (float)accel[2] - acc_bias_counts[2];

         // Convert to g and m/s²
         float ax_g = ax_c / ACCEL_LSB_PER_G;
         float ay_g = ay_c / ACCEL_LSB_PER_G;
         float az_g = az_c / ACCEL_LSB_PER_G;

         // Optional smoothing for prettier printing
         ax_g_f = EMA_ALPHA*ax_g + (1.0f-EMA_ALPHA)*ax_g_f;
         ay_g_f = EMA_ALPHA*ay_g + (1.0f-EMA_ALPHA)*ay_g_f;
         az_g_f = EMA_ALPHA*az_g + (1.0f-EMA_ALPHA)*az_g_f;

         ax_ms2 = ax_g_f * G_IN_MS2;
         ay_ms2 = ay_g_f * G_IN_MS2;
         az_ms2 = az_g_f * G_IN_MS2;
     }

     if (icm42605_read_gyro(gyro) == HAL_OK) {
         // Bias-correct in COUNTS, then convert to dps
         const float gx_c = (float)gyro[0] - gyr_bias_counts[0];
         const float gy_c = (float)gyro[1] - gyr_bias_counts[1];
         const float gz_c = (float)gyro[2] - gyr_bias_counts[2];

         const float gx_dps_raw = gx_c / GYRO_LSB_PER_DPS;
         const float gy_dps_raw = gy_c / GYRO_LSB_PER_DPS;
         const float gz_dps_raw = gz_c / GYRO_LSB_PER_DPS;

         // Optional smoothing
         gx_dps_f = EMA_ALPHA*gx_dps_raw + (1.0f-EMA_ALPHA)*gx_dps_f;
         gy_dps_f = EMA_ALPHA*gy_dps_raw + (1.0f-EMA_ALPHA)*gy_dps_f;
         gz_dps_f = EMA_ALPHA*gz_dps_raw + (1.0f-EMA_ALPHA)*gz_dps_f;

         gx_dps = gx_dps_f; gy_dps = gy_dps_f; gz_dps = gz_dps_f;
     }

     // --- Angles from corrected accel (in g) ---
     float ax_g_use = ax_ms2 / G_IN_MS2;
     float ay_g_use = ay_ms2 / G_IN_MS2;
     float az_g_use = az_ms2 / G_IN_MS2;

     pitch_deg = atan2f(-ax_g_use, sqrtf(ay_g_use*ay_g_use + az_g_use*az_g_use)) * (180.0f / M_PI);
     roll_deg  = atan2f( ay_g_use, az_g_use ) * (180.0f / M_PI);

     // Print
     printf("[IMU: Accel] (m/s²): X=%.2f Y=%.2f Z=%.2f\r\n", ax_ms2, ay_ms2, az_ms2);
     printf("[IMU: Gyro]  (°/s):  X=%.2f Y=%.2f Z=%.2f\r\n", gx_dps, gy_dps, gz_dps);
     printf("[IMU: Angles] (deg):  Pitch=%.2f Roll=%.2f\r\n",  pitch_deg, roll_deg);

    HAL_GPIO_TogglePin(GPIOA, LED_Pin);
    HAL_Delay(100); // ~1 Hz refresh for readability

    // --- BMP280 read (5 Hz) ---
    if ((int32_t)(HAL_GetTick() - next_bmp) >= 0) {
        next_bmp += 200;

        float t_c, p_pa;
        if (bmp280_read_temp_press(&bmp, &t_c, &p_pa) == HAL_OK) {
            float alt_m = bmp280_altitude_m_from_pa(p_pa, SEA_LEVEL_PA);
            printf("[BMP280] T=%.2f C  P=%.1f Pa  Alt=%.1f m\r\n", t_c, p_pa, alt_m);
        }
    }
  }
    /* USER CODE END WHILE */

}

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
/* USER CODE BEGIN 4 */
static void BMP280_AppInit(void)
{
    if (bmp280_init_spi(&bmp, &hspi3, BMP280_CS_GPIO, BMP280_CS_PIN) != HAL_OK) {
        Error_Handler();
    }
    // Write CONFIG while device is in sleep (after reset)
    bmp280_set_config(&bmp, BMP280_TSB_125_MS, BMP280_FILTER_4, false);
    // Start continuous conversions
    bmp280_set_ctrl_meas(&bmp, BMP280_OSRS_X1, BMP280_OSRS_X4, BMP280_MODE_NORMAL);

    // Sanity read
    float t, p;
    if (bmp280_read_temp_press(&bmp, &t, &p) == HAL_OK) {
        float alt = bmp280_altitude_m_from_pa(p, SEA_LEVEL_PA);
        (void)alt;
    }
}
/* USER CODE END 4 */
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


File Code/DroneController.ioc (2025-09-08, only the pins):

Mcu.UserName=STM32F411CEUx
PA1.GPIO_Label=LED
PA1.Signal=GPIO_Output
PA11.Signal=USB_OTG_FS_DM
PA12.Signal=USB_OTG_FS_DP
PA13.Signal=SYS_JTMS-SWDIO
PA14.Signal=SYS_JTCK-SWCLK
PA15.GPIO_Label=NSS3
PA15.Signal=GPIO_Output
PA2.Signal=USART2_TX
PA3.Signal=USART2_RX
PA4.GPIO_Label=NSS1
PA4.Signal=GPIO_Output
PA5.Signal=SPI1_SCK
PA6.Signal=SPI1_MISO
PA7.Signal=SPI1_MOSI
PB1.GPIO_Label=NSS5
PB1.Signal=GPIO_Output
PB12.GPIO_Label=NSS2
PB12.Signal=GPIO_Output
PB13.Signal=SPI2_SCK
PB14.Signal=SPI2_MISO
PB15.Signal=SPI2_MOSI
PB3.Signal=SPI3_SCK
PB4.Signal=SPI3_MISO
PB5.Signal=SPI3_MOSI
PB6.Signal=USART1_TX
PB7.Signal=USART1_RX

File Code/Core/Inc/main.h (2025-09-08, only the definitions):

#define LED_Pin GPIO_PIN_1
#define LED_GPIO_Port GPIOA
#define NSS1_Pin GPIO_PIN_4
#define NSS1_GPIO_Port GPIOA
#define NSS5_Pin GPIO_PIN_1
#define NSS5_GPIO_Port GPIOB
#define NSS2_Pin GPIO_PIN_12
#define NSS2_GPIO_Port GPIOB
#define NSS3_Pin GPIO_PIN_15
#define NSS3_GPIO_Port GPIOA

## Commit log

2025-07-22 Modified BMP280 wiring, cleaned up schematic
    [DroneController.kicad_pcb, DroneController.kicad_sch]
2025-08-07 ESC Board: Major overhauls to schematic, preliminary layout
    [ESC1.kicad_sch, ESC_Board.kicad_pcb, ESC_Board.kicad_sch]
2025-08-07 Finalized Layout for ESC Board
    [ESC_Board.kicad_pcb, ESC_Board.kicad_sch]
2025-08-07 Update README.md
    Updated README with media of the completed ESC Board and the Flight Computer Board.
2025-08-09 Optimized Signal Integrity, added stichting vias, and stiching capacitors between PWR and GND layers
    [DroneController.kicad_pcb, ESC_Board.kicad_pcb, ESC_Board.kicad_sch]
2025-09-02 Added Codebase, Reorganized file directory to support added code
    [BOM_DroneController_Final.csv, COMM-SMD_LORA1276-C1-915MHZ.step, CONN-SMD_5019.step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]
2025-09-04 Added working code for IMU and Barometer, displaying acceleration,gyro, pitch, yaw, temperature, altitude, pressure
2025-09-08 Changed ESC Board Connector to XT30-M from XT30-F
    [ESC_Board.kicad_pcb]
2025-09-08 Added working code for IMU, Barometer, SX1276, W25 Flash Memory
2026-02-08 Added CAD models for PCB and Drone

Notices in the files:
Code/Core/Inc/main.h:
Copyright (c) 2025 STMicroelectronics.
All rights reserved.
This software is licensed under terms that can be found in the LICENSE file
